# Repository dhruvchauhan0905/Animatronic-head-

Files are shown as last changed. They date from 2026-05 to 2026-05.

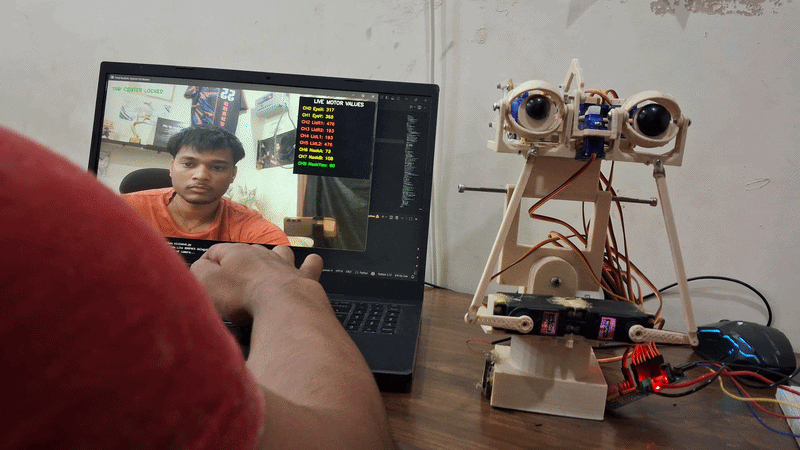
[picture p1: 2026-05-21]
media/Video/gif1-ezgif.com-speed.gif

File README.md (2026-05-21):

# Animatronic-head-
# 🤖 Animatronic Robotic Head — Real-Time Face Tracking

Demo video : https://youtu.be/sOe_zQ1-tDE

> A 9-servo animatronic head that mirrors human facial movements in real time using MediaPipe face mesh tracking, Arduino, and a PCA9685 PWM driver. Includes a full calibration system, physics-based motion control, and predictive compensation for smooth, lag-free neck movement.

## Features

- **Real-time face tracking** via MediaPipe Face Mesh (468 landmarks + iris refinement)
- **9-servo system** — eyes (X/Y), left/right eyelids (2 servos each), and a 3-DOF neck (tilt, vertical, yaw)
- **Calibration phase** — 2-step Y/N confirmation to set user neutral pose before tracking begins
- **Center locking** — neck snaps to neutral when head is stationary, preventing servo drift
- **Eyelid blink detection** — threshold-based open/close state with smooth interpolation
- **Yaw-corrected eye Y** — blends toward individual eye ratio when head turns sharply
- **Perspective-aware eyelid swap** — swaps left/right eyelid state when head turns beyond ±48° yaw
- **Physics-based motion** — per-channel speed, acceleration, and deceleration constants
- **Throttled neck updates** — CH6/CH7 commit target every 17 ms (40% read reduction) to eliminate jitter
- **Predictive target compensation** — 40 ms lookahead cancels serial + processing lag on neck servos
- **Live motor overlay** — real-time HUD showing all 9 channel values colour-coded by deviation

---

## System Architecture

```
Webcam (1280×720)
  │
  ▼
MediaPipe FaceMesh  ──  refine_landmarks=True  ──  iris landmarks 468, 473
  │
  ├─ Iris position (relative to eye corners)       →  Eye X / Y target
  ├─ Forehead / nose / chin distance ratio         →  Neck vertical target
  ├─ Face tilt angle (left/right face points)      →  Neck tilt target
  ├─ Nose-to-face asymmetry ratio                  →  Neck yaw target
  └─ Eyelid landmark distance (159↔145, 386↔374)  →  Blink state
  │
  ▼
Python tracking script
  │  Rolling average smoothing (window = 10 frames)
  │  Center lock, dead zones, yaw damping
  │  Packet: "EyeX,EyeY,LidR1,LidR2,LidL1,LidL2,Neck6,Neck7,Neck8\n"
  │
  ▼
PySerial  ──  COM9  ──  115200 baud
  │
  ▼
Arduino Uno
  │  readVisionSerial()  — parses comma-delimited packet
  │  updateNeck67()      — throttle + predictive commit every 17 ms
  │  driveEyeY()         — hybrid physics for CH1
  │  drivePhysics67()    — physics for CH6/CH7
  │  drivePhysics8()     — physics for CH8
  │  loop delay(10)      — 100 Hz
  │
  ▼
PCA9685  (I2C, 60 Hz PWM)
  │
  ├─ CH0  Eye X     (direct pulse)
  ├─ CH1  Eye Y     (physics)
  ├─ CH2  LidR1     (direct pulse)
  ├─ CH3  LidR2     (direct pulse)
  ├─ CH4  LidL1     (direct pulse)
  ├─ CH5  LidL2     (direct pulse)
  ├─ CH6  Neck A    (throttle + physics)
  ├─ CH7  Neck B    (throttle + physics)
  └─ CH8  Neck Yaw  (physics)
```

---

## Channel Mapping

| Channel | Name | Drive type | Neutral | Range | Notes |
|---|---|---|---|---|---|
| CH0 | Eye X | Direct pulse | 330 | 195 – 465 | Horizontal iris tracking |
| CH1 | Eye Y | Physics | 350 | 260 – 445 | Vertical iris tracking |
| CH2 | Right Eyelid 1 | Direct pulse | 330 | 193 – 477 | Open = 477, Closed = 330 |
| CH3 | Right Eyelid 2 | Direct pulse | 330 | 193 – 477 | Open = 193, Closed = 330 |
| CH4 | Left Eyelid 1 | Direct pulse | 330 | 193 – 477 | Open = 193, Closed = 330 |
| CH5 | Left Eyelid 2 | Direct pulse | 330 | 193 – 477 | Open = 477, Closed = 330 |
| CH6 | Neck A (vertical + tilt) | Throttled physics | 90° | 5° – 175° | Paired with CH7 |
| CH7 | Neck B (vertical + tilt) | Throttled physics | 90° | 5° – 175° | Paired with CH6 |
| CH8 | Neck Yaw | Physics | 90° | 3° – 175° | Maps yaw ratio −0.30 → 0.30 |

> CH6 and CH7 are driven together. Vertical lift adds to both equally; tilt adds equally in the same direction, producing roll from the difference.

---

## Serial Packet Format

Python sends one ASCII line per frame over serial:

```
{EyeX},{EyeY},{LidR1},{LidR2},{LidL1},{LidL2},{Neck6},{Neck7},{NeckYaw}\n
```

Example:
```
328,352,477,193,193,477,94,86,91
```

CH0–CH5 are raw PCA9685 pulse counts. CH6–CH8 are angles in degrees (0–180), converted to pulses on the Arduino side via `angleToPulse()`.

> ⚠️ **Baud rate mismatch in current code:** `face_tracker.py` opens serial at **9600** but `animatronic_head.ino` uses `Serial.begin(115200)`. Set both to **115200** — see Setup section.

---

## Motion Tuning

### Arduino — CH1 Eye Y physics

```cpp
float eyeMaxSpeed      = 9.5;    // max degrees per loop tick
float eyeAccel         = 0.55;   // acceleration ramp
float eyeDecel         = 0.78;   // deceleration multiplier
float eyeDecelDistance = 10;     // distance from target to begin braking
```

### Arduino — CH6 / CH7 Neck (vertical + tilt)

```cpp
float maxSpeed67      = 9.52;    // 40% raised from original 6.8
float accel67         = 0.336;   // 40% raised from original 0.24
float decel67         = 0.84;
float decelDistance67 = 16;

const unsigned long NECK67_INTERVAL = 17;    // ms — commit throttle
const float         LOOKAHEAD_SEC   = 0.040; // 40 ms predictive lead
```

Incoming CH6/CH7 targets are **averaged** across all serial packets received in the 17 ms window, then a velocity estimate is computed and the target is nudged 40 ms ahead before it is handed to the physics driver. This removes the lag introduced by serial buffering and processing delay.

### Arduino — CH8 Neck Yaw

```cpp
float maxSpeed8      = 5.6;
float accel8         = 0.18;
float decel8         = 0.86;
float decelDistance8 = 18;
```

### Python — Smoothing factors

| Parameter | Value | Effect |
|---|---|---|
| Eye X blend | 0.90 | Very fast, near-instant |
| Eye Y blend | 0.67 | Slightly damped |
| Eyelid blend | 0.39 | Slow, natural-looking blink |
| Yaw / vertical / tilt window | 10 frames | Rolling average |

### Python — Center lock thresholds

| Lock | Engages when | Releases when |
|---|---|---|
| Neck center (CH6/CH7) | total error < 5 | total error > 13 |
| Yaw center (CH8) | \|avgYaw\| < 0.04 | \|avgYaw\| > 0.09 |

When locked, the corresponding channels hold exactly at their neutral value regardless of small sensor noise.

---

## Calibration

On launch the script runs a calibration loop before tracking starts.

1. Sit in your neutral resting position facing the camera
2. Wait at least 10 seconds for stable face detection
3. Press **`Y`** — first confirmation, captures current pose as tentative reference
4. Press **`Y`** again — confirms and locks the reference zero
5. Press **`N`** at any step to reset and recapture

The calibration stores:

| Variable | What it captures |
|---|---|
| `baseEyeRelX / baseEyeRelY` | Iris position normalised to eye corner span |
| `baseTop / baseBottom` | Forehead-to-nose and nose-to-chin ratios (normalised to face width) |
| `baseTilt` | Face roll angle in degrees |
| `baseYaw` | Nose-to-face-edge asymmetry ratio |

All live values are computed as **deltas from this reference**, so the robot stays centred regardless of where you sit relative to the camera.

---

## Eyelid Logic

Blink detection uses vertical distance between eyelid landmarks:

```
Left eye:   lm[159] (top lid)  ↔  lm[145] (bottom lid)
Right eye:  lm[386] (top lid)  ↔  lm[374] (bottom lid)
```

| Event | Threshold | Result |
|---|---|---|
| Opening | distance > 0.0132 | State → Open |
| Closing | distance < 0.0108 | State → Closed |

Hysteresis between the two thresholds prevents rapid state flicker.

When **yaw exceeds ±48°**, the left and right eyelid states are swapped — at that angle the camera perspective reverses which eye appears to be blinking.

---

## Hardware

### Components

| Component | Qty | Notes |
|---|---|---|
| Arduino Uno | 1 | Microcontroller |
| PCA9685 16-ch PWM driver | 1 | I2C, 60 Hz |
| MG996R servo | 3 | Neck — CH6, CH7, CH8 |
| SG90 servo | 6 | Eyes — CH0, CH1 + eyelids — CH2–CH5 |
| 5V 5A SMPS | 1 | Powers servos via PCA9685 V+ terminal |
| Webcam | 1 | Face tracking input |

### Wiring

```
Arduino Uno              PCA9685
-----------              -------
5V          ──────────▶  VCC
GND         ──────────▶  GND
A4 (SDA)    ──────────▶  SDA
A5 (SCL)    ──────────▶  SCL

External PSU (5V 5A)     PCA9685
--------------------     -------
+           ──────────▶  V+  (power terminal)
−           ──────────▶  GND (power terminal)
```

> ⚠️ Never power servos from Arduino 5V. Always use the external PSU through the PCA9685 V+ terminal.

### Pulse range

```cpp
#define SERVOMIN 140   // ≈ 0°
#define SERVOMAX 520   // ≈ 180°
```

---

## Setup

### 1. Python dependencies

```bash
pip install mediapipe opencv-python pyserial
```

### 2. Arduino libraries

Install via Arduino Library Manager:
- `Adafruit PWM Servo Driver Library`
- `Wire` (built-in)

### 3. Upload firmware

Open `firmware/animatronic_head.ino`, select **Arduino Uno** and your COM port, then upload.

### 4. Fix baud rate (important)

In `tracking/face_tracker.py`, change line 4:
```python
# Before
arduino = serial.Serial('COM9', 9600)

# After
arduino = serial.Serial('COM9', 115200)   # match Arduino sketch
```

Also update `'COM9'` to your actual port (`/dev/ttyUSB0` on Linux, `/dev/cu.usbmodem...` on Mac).

### 5. Run the tracker

```bash
python tracking/face_tracker.py
```

Follow the calibration prompt on screen. Press **`Y`** twice to confirm neutral pose. Press **`ESC`** to quit.

---

## Repository Structure

```
animatronic-head/
├── README.md
├── firmware/
│   └── animatronic_head.ino      # Arduino sketch
├── tracking/
│   └── face_tracker.py           # Python face tracking + serial bridge
├── cad/
│   ├── eye_hemisphere.stl
│   ├── neck_mechanism.stl
│   └── source/                   # Fusion 360 .f3d source files
├── media/
│   ├── demo.gif
│   ├── wiring_diagram.svg
│   └── photos/
└── docs/
    └── wiring.md
```

---

## 3D Printing

| Setting | Value |
|---|---|
| Material | PLA |
| Layer height | 0.2 mm |
| Infill | 20% |
| Supports | Yes (neck assembly) |

---

## Author

**Dhruv** — Engineering student, Delhi  
Interests: robotics, animatronics, hardware systems  
GitHub: [@dhruvchauhan0905](https://github.com/dhruvchauhan0905)

---

## License

MIT License — free to use, modify, and build on.

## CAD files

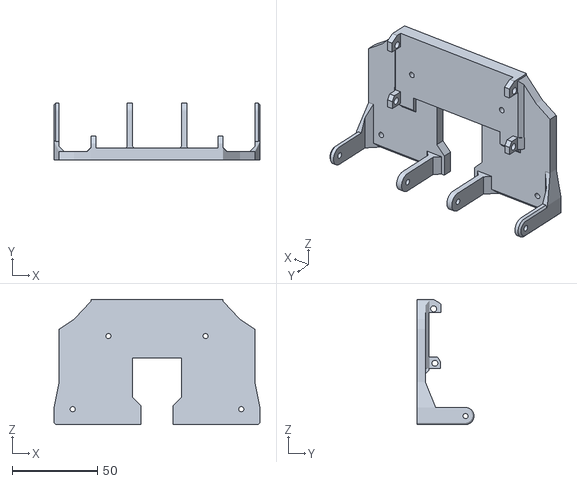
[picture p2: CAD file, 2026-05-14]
cad/eyes/Main Base.stl
121.0 x 33.5 x 73.5

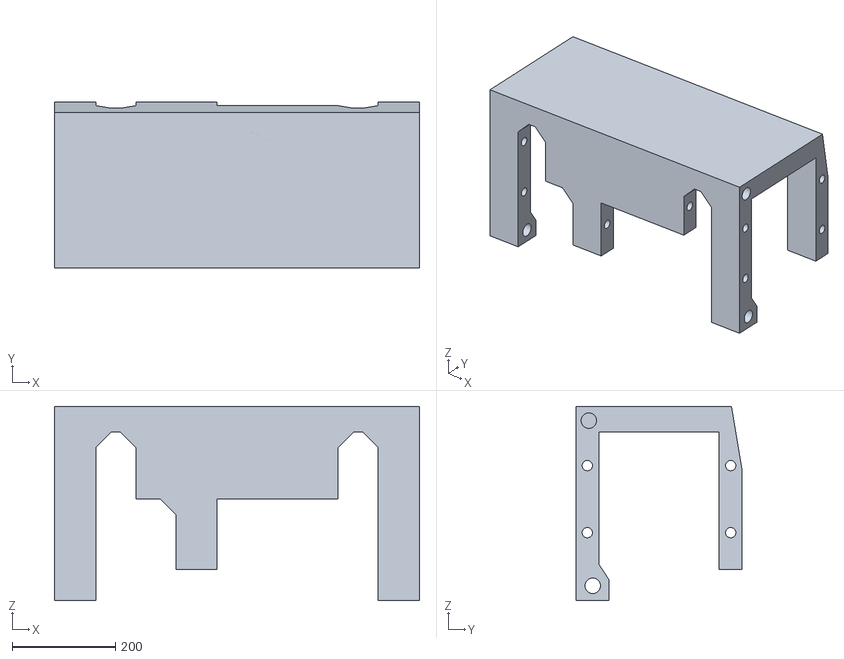
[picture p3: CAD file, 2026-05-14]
cad/eyes/Servo Block2.stl
707.7 x 321.0 x 376.8

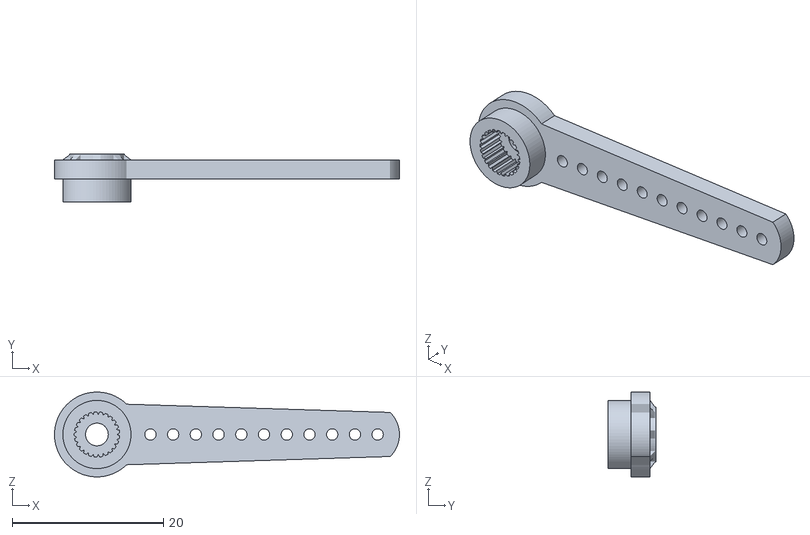
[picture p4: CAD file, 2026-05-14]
cad/neck/servohorn(+2).stl
45.5 x 6.30 x 11.2

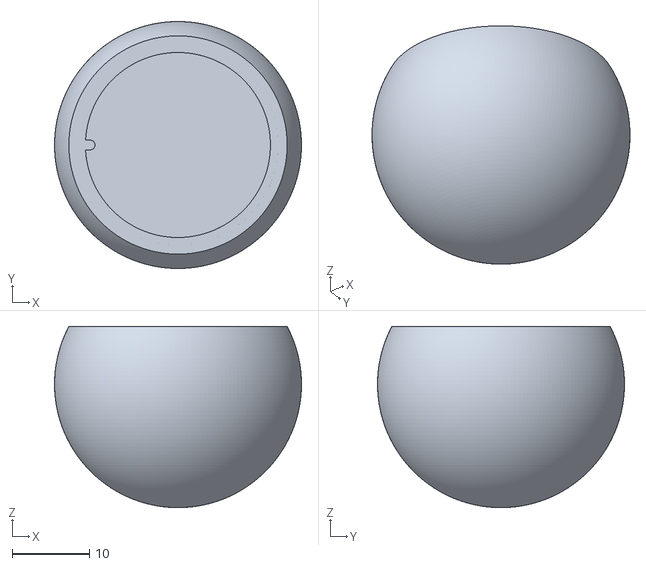
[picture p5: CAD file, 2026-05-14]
cad/eyes/PlaceHolder Eye (x2).stl
32.0 x 32.0 x 23.5

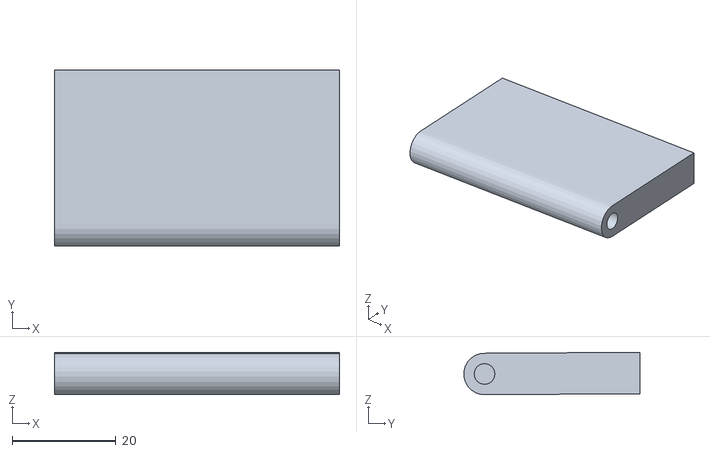
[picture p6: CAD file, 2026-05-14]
cad/neck/felxion and extension lever_.stl
55.0 x 34.0 x 8.17

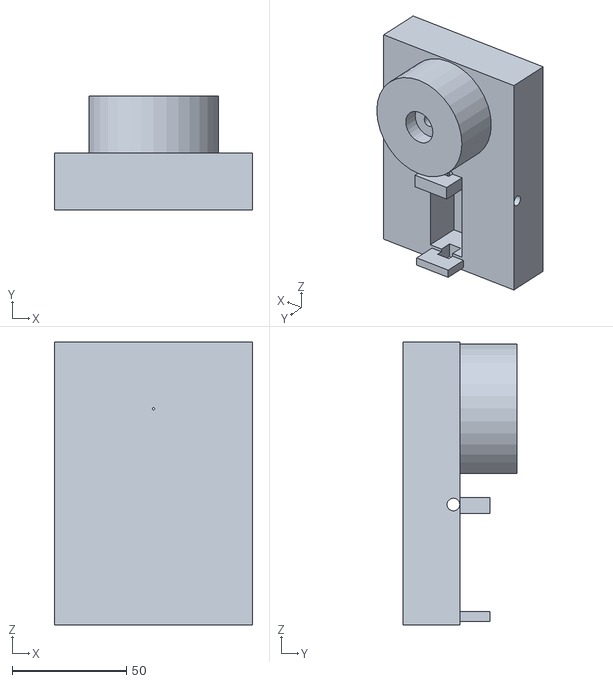
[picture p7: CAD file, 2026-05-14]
cad/neck/neckbase.stl
86.5 x 50.0 x 123.6

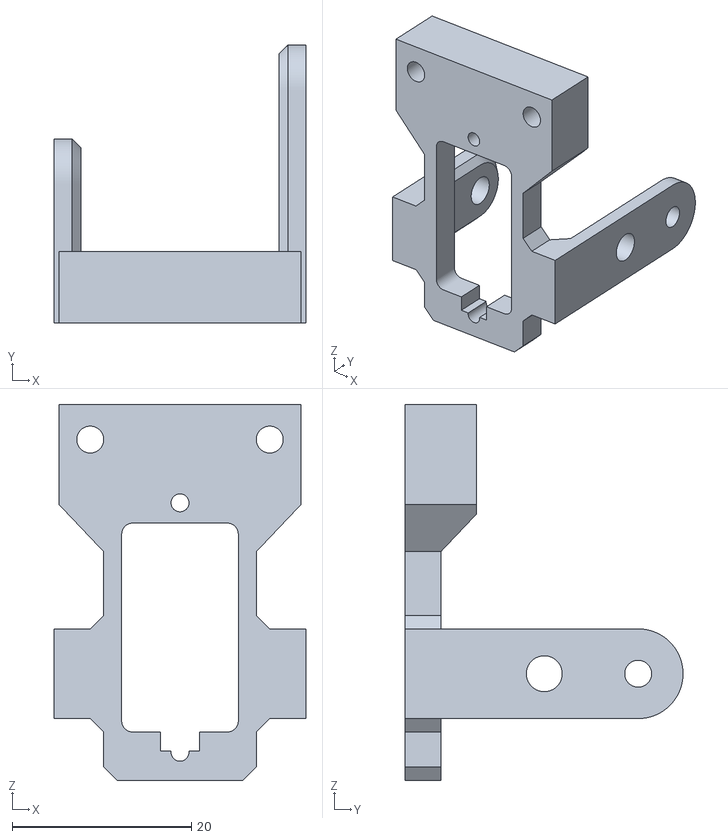
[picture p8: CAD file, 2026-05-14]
cad/eyes/Sub Base.stl
28.1 x 31.0 x 41.9

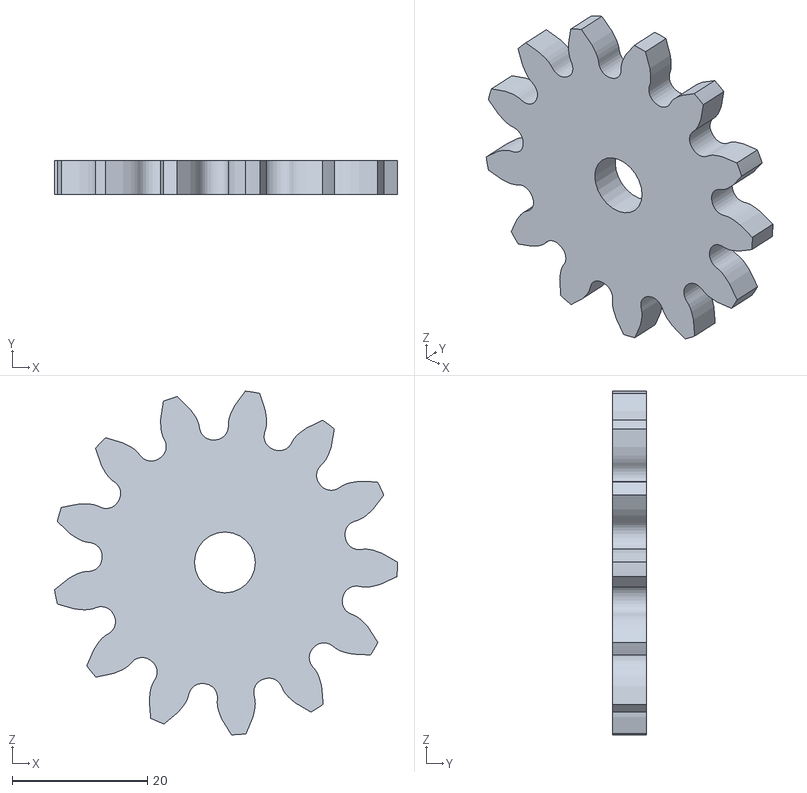
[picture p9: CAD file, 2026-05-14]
cad/neck/drivergear for roatation _.stl
50.7 x 5.00 x 50.8

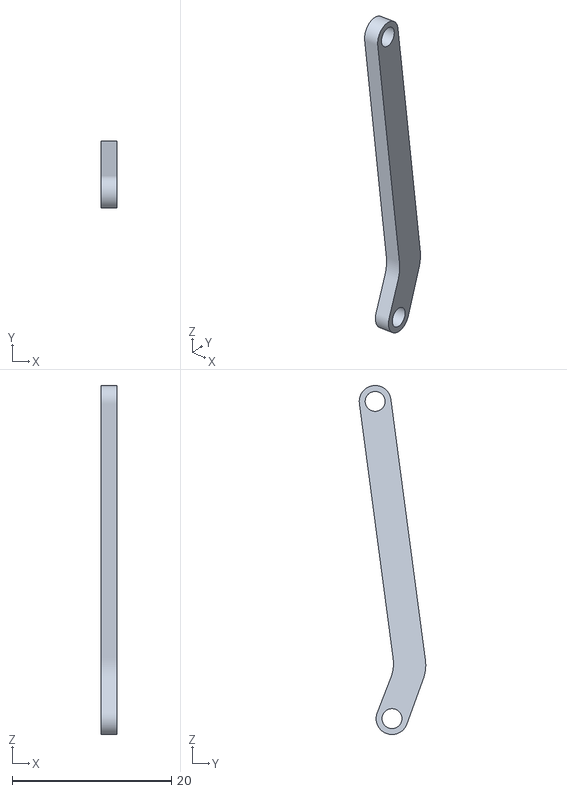
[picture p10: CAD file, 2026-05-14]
cad/eyes/Top Lid Link (x2).stl
2.00 x 8.36 x 43.9

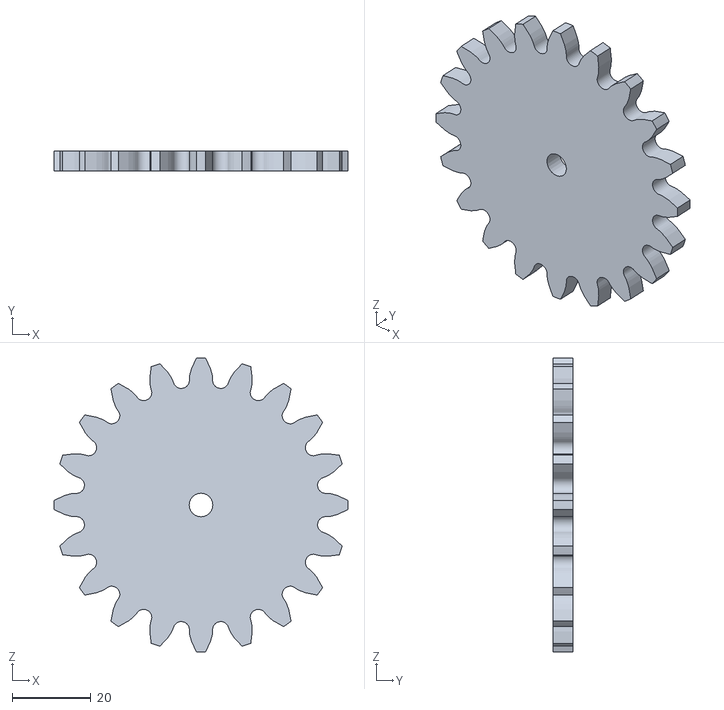
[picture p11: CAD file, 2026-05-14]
cad/neck/drivengear for roation _.stl
74.8 x 5.00 x 74.8

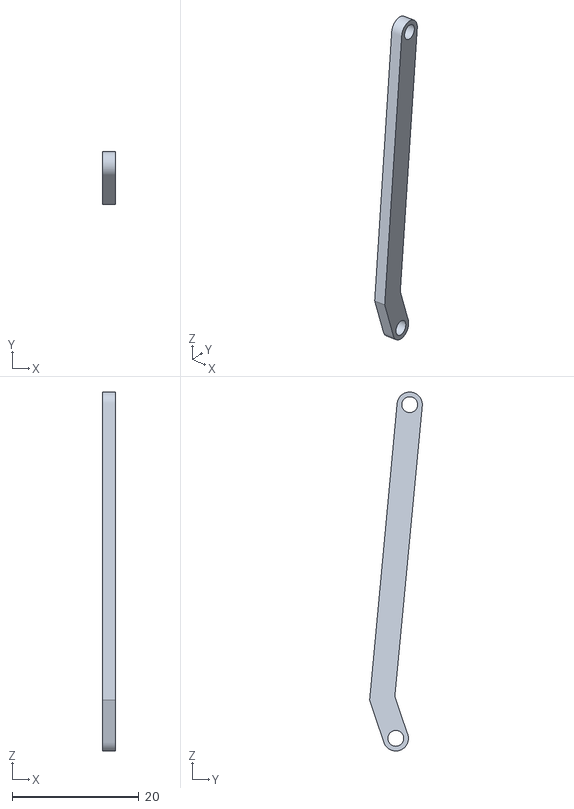
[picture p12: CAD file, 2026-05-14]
cad/eyes/Bottom Lid Link (x2).stl
2.00 x 8.33 x 56.7

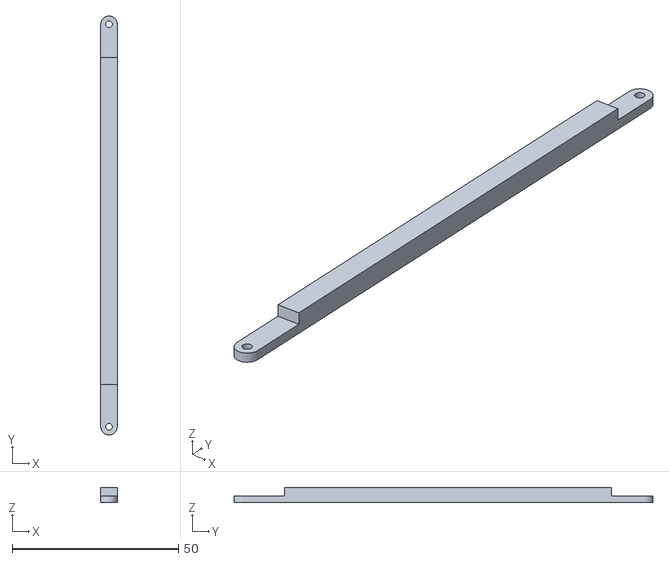
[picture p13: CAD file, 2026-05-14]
cad/neck/flexion and extensions pulley(+2)_.stl
5.00 x 126.0 x 4.50

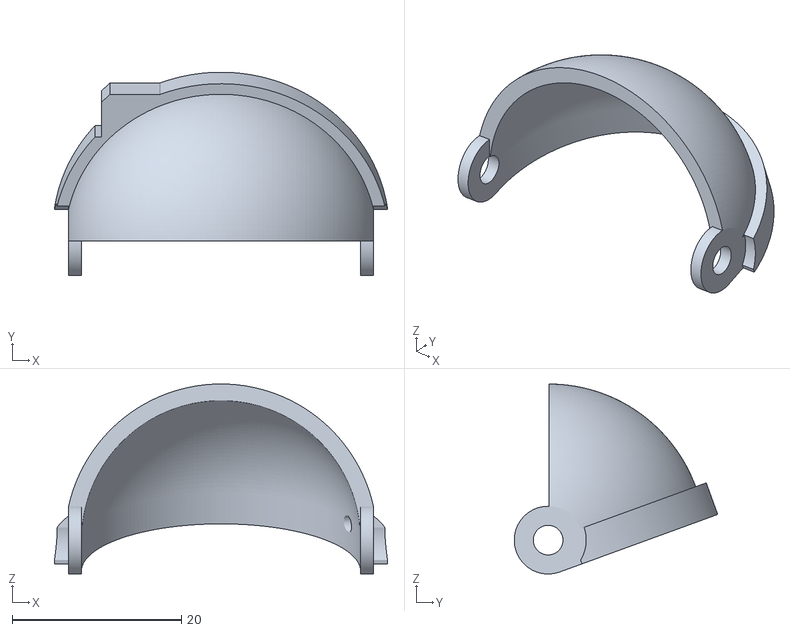
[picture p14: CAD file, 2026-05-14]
cad/eyes/Top Right Lid.stl
39.3 x 24.0 x 22.4

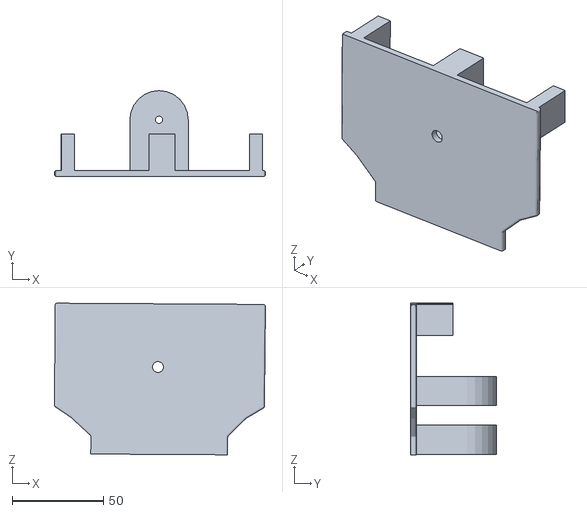
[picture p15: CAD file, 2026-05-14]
cad/neck/subbase.stl
115.6 x 47.0 x 83.1

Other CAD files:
cad/eyes/Three-Point Connector.stl
cad/neck/sidebend lever_.stl
cad/eyes/Eye Holder.stl
cad/eyes/Bottom Right Lid.stl
cad/eyes/Bottom Left Lid.stl
cad/eyes/Eye Adaptor (x2).stl
cad/eyes/Fork (x2).stl
cad/eyes/Top Left Lid.stl
cad/eyes/Y-Arm.stl

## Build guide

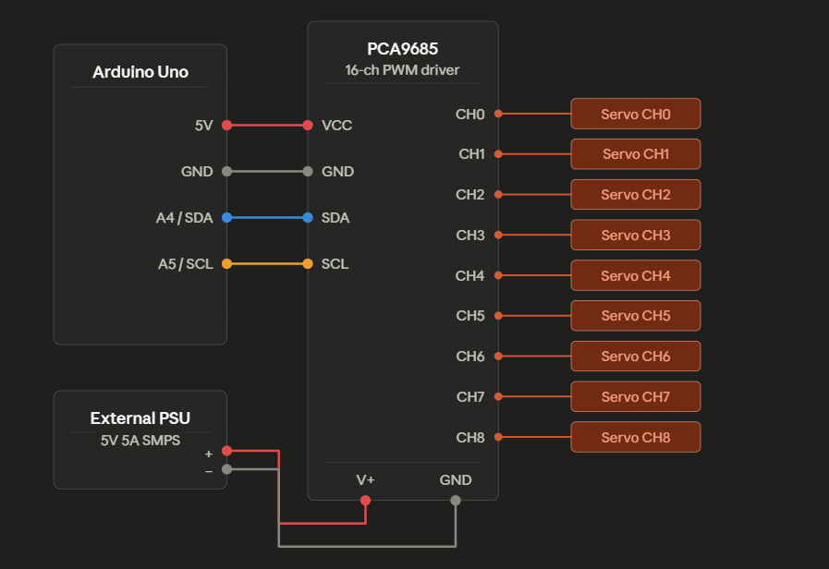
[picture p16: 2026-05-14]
media/wiring diagram .png

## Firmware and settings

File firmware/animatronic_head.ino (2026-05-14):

#include <Wire.h>
#include <Adafruit_PWMServoDriver.h>

Adafruit_PWMServoDriver pwm = Adafruit_PWMServoDriver();

#define SERVOMIN 140
#define SERVOMAX 520

int pulseX = 330, pulseY = 375;
int ch2 = 330, ch3 = 330, ch4 = 330, ch5 = 330;

// ===== CH1 HYBRID EYE Y — original unchanged =====
float eyeYTarget = 375;
float eyeYPos = 375;
float eyeYVel = 0;

// ===== CH8 YAW — original unchanged =====
float target8 = 90, pos8 = 90, vel8 = 0;

String incoming = "";

// ===== CH1 EYE Y CONSTANTS — original unchanged =====
float eyeMaxSpeed      = 9.5;
float eyeAccel         = 0.55;
float eyeDecel         = 0.78;
float eyeDecelDistance = 10;

// ===== CH6/CH7 CONSTANTS — speed raised 40% from original =====
// Original: maxSpeed67=6.8, accel67=0.24
// x1.4   : maxSpeed67=9.52, accel67=0.336
float maxSpeed67      = 9.52;
float accel67         = 0.336;
float decel67         = 0.84;   // original unchanged
float decelDistance67 = 16;     // original unchanged

// ===== CH8 CONSTANTS — original unchanged =====
float maxSpeed8      = 5.6;
float accel8         = 0.18;
float decel8         = 0.86;
float decelDistance8 = 18;

// ==========================================================
//  CH6/CH7 THROTTLE + PREDICTIVE COMPENSATION
//
//  40% read reduction: loop runs every 10ms (100Hz).
//  Original = 100 target updates/sec.
//  40% less  = 60 updates/sec = update every 17ms.
//  So ch6/ch7 target only commits every 17ms.
//
//  Predictive compensation: every commit we calculate how
//  fast the target is moving (degrees/sec) and look 40ms
//  ahead. Motor aims at where the neck WILL be, not where
//  it was — this cancels the serial+processing lag.
// ==========================================================
const unsigned long NECK67_INTERVAL = 17;   // ms — 40% less than 10ms loop
const float         LOOKAHEAD_SEC   = 0.040; // 40ms prediction window

float accum6 = 0, accum7 = 0;
int   accumCount = 0;

float committedTarget6 = 90.0;
float committedTarget7 = 90.0;

float prevAvg6 = 90.0, prevAvg7 = 90.0;

float pos6 = 90, vel6 = 0;
float pos7 = 90, vel7 = 0;

unsigned long lastNeck67Update = 0;

// ----------------------------------------------------------
int angleToPulse(float angle) {
  return map((int)angle, 0, 180, SERVOMIN, SERVOMAX);
}

// ----------------------------------------------------------
void readVisionSerial() {
  while (Serial.available()) {
    char c = Serial.read();

    if (c == '\n') {
      int p1 = incoming.indexOf(',');
      int p2 = incoming.indexOf(',', p1 + 1);
      int p3 = incoming.indexOf(',', p2 + 1);
      int p4 = incoming.indexOf(',', p3 + 1);
      int p5 = incoming.indexOf(',', p4 + 1);
      int p6 = incoming.indexOf(',', p5 + 1);
      int p7 = incoming.indexOf(',', p6 + 1);
      int p8 = incoming.indexOf(',', p7 + 1);

      if (p1>0 && p2>0 && p3>0 && p4>0 && p5>0 && p6>0 && p7>0 && p8>0) {
        pulseX = incoming.substring(0,      p1).toInt();
        pulseY = incoming.substring(p1 + 1, p2).toInt();
        ch2    = incoming.substring(p2 + 1, p3).toInt();
        ch3    = incoming.substring(p3 + 1, p4).toInt();
        ch4    = incoming.substring(p4 + 1, p5).toInt();
        ch5    = incoming.substring(p5 + 1, p6).toInt();

        // Accumulate ch6/ch7 — commit happens on timer below
        float raw6 = incoming.substring(p6 + 1, p7).toFloat();
        float raw7 = incoming.substring(p7 + 1, p8).toFloat();
        target8    = incoming.substring(p8 + 1).toFloat();

        eyeYTarget = pulseY;

        accum6 += raw6;
        accum7 += raw7;
        accumCount++;
      }
      incoming = "";
    }
    else {
      incoming += c;
    }
  }
}

// ----------------------------------------------------------
//  Runs every loop. Only commits a new target to ch6/ch7
//  every 17ms (40% less than 10ms loop = 40% read reduction).
//  Applies predictive compensation to remove lag.
// ----------------------------------------------------------
void updateNeck67() {
  unsigned long now = millis();
  if (now - lastNeck67Update < NECK67_INTERVAL) return;

  float dt = (now - lastNeck67Update) / 1000.0;  // actual elapsed seconds
  lastNeck67Update = now;

  if (accumCount > 0) {
    float avg6 = accum6 / accumCount;
    float avg7 = accum7 / accumCount;

    // Velocity of target in degrees/sec
    float targetVel6 = (avg6 - prevAvg6) / dt;
    float targetVel7 = (avg7 - prevAvg7) / dt;

    // Predict where target will be LOOKAHEAD_SEC from now
    // This compensates for serial delay + processing delay
    float predicted6 = avg6 + targetVel6 * LOOKAHEAD_SEC;
    float predicted7 = avg7 + targetVel7 * LOOKAHEAD_SEC;

    // Clamp prediction to safe servo range
    committedTarget6 = constrain(predicted6, 5.0, 175.0);
    committedTarget7 = constrain(predicted7, 5.0, 175.0);

    prevAvg6 = avg6;
    prevAvg7 = avg7;

    accum6 = 0;
    accum7 = 0;
    accumCount = 0;
  }
}

// ===== ORIGINAL PHYSICS FUNCTIONS — structure unchanged =====

void driveEyeY(float &pos, float &vel, float target) {
  float error = target - pos;
  if (abs(error) > eyeDecelDistance) {
    vel += (error > 0 ? eyeAccel : -eyeAccel);
  } else {
    vel *= eyeDecel;
  }
  vel = constrain(vel, -eyeMaxSpeed, eyeMaxSpeed);
  if (abs(error) < 0.3) vel = 0;
  pos += vel;
  pos  = constrain(pos, 260, 445);
}

void drivePhysics67(float &pos, float &vel, float target,
                    float maxSpeed, float accel, float decel, float decelDistance) {
  float error = target - pos;
  if (abs(error) > decelDistance) {
    vel += (error > 0 ? accel : -accel);
  } else {
    vel *= decel;
  }
  vel = constrain(vel, -maxSpeed, maxSpeed);
  if (abs(error) < 0.4) vel = 0;
  pos += vel;
  pos  = constrain(pos, 3, 178);
}

void drivePhysics8(float &pos, float &vel, float target,
                   float maxSpeed, float accel, float decel, float decelDistance) {
  float error = target - pos;
  if (abs(error) > decelDistance) {
    vel += (error > 0 ? accel : -accel);
  } else {
    vel *= decel;
  }
  vel = constrain(vel, -maxSpeed, maxSpeed);
  if (abs(error) < 0.4) vel = 0;
  pos += vel;
  pos  = constrain(pos, 3, 178);
}

// ----------------------------------------------------------
void setup() {
  Serial.begin(115200);
  pwm.begin();
  pwm.setPWMFreq(60);
  lastNeck67Update = millis();
}

void loop() {

  readVisionSerial();
  updateNeck67();

  // CH0 — direct, original
  pwm.setPWM(0, 0, pulseX);

  // CH1 — hybrid eye Y, original
  driveEyeY(eyeYPos, eyeYVel, eyeYTarget);
  pwm.setPWM(1, 0, (int)eyeYPos);

  // CH2-5 — eyelids direct, original
  pwm.setPWM(2, 0, ch2);
  pwm.setPWM(3, 0, ch3);
  pwm.setPWM(4, 0, ch4);
  pwm.setPWM(5, 0, ch5);

  // CH6/CH7 — throttled + predicted target, original physics function
  drivePhysics67(pos6, vel6, committedTarget6, maxSpeed67, accel67, decel67, decelDistance67);
  drivePhysics67(pos7, vel7, committedTarget7, maxSpeed67, accel67, decel67, decelDistance67);
  pwm.setPWM(6, 0, angleToPulse(pos6));
  pwm.setPWM(7, 0, angleToPulse(pos7));

  // CH8 — yaw, original unchanged
  drivePhysics8(pos8, vel8, target8, maxSpeed8, accel8, decel8, decelDistance8);
  pwm.setPWM(8, 0, angleToPulse(pos8));

  delay(10);
}

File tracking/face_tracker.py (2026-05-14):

import cv2
import mediapipe as mp
import serial
import time
import math

arduino = serial.Serial('COM9', 9600)
time.sleep(2)

mp_face_mesh = mp.solutions.face_mesh
face_mesh = mp_face_mesh.FaceMesh(refine_landmarks=True)

cap = cv2.VideoCapture(0)

ROBOT_EYE_X_CENTER = 330
ROBOT_EYE_Y_CENTER = 350
ROBOT_NECK6_CENTER = 90
ROBOT_NECK7_CENTER = 90
ROBOT_NECK8_CENTER = 90

smoothX = ROBOT_EYE_X_CENTER
smoothY = ROBOT_EYE_Y_CENTER
L2 = L3 = R4 = R5 = 330

targetNeck6 = ROBOT_NECK6_CENTER
targetNeck7 = ROBOT_NECK7_CENTER
targetNeck8 = ROBOT_NECK8_CENTER

yawHistory = []
verticalHistory = []
tiltHistory = []

lastLeftX = None
lastRightX = None

baseTop = 0
baseBottom = 0
baseTilt = 0
baseYaw = 0
baseEyeRelX = 0
baseEyeRelY = 0

neckCenterLocked = False
yawCenterLocked = False

leftEyeStateOpen = True
rightEyeStateOpen = True

def map_range(value, in_min, in_max, out_min, out_max):
    value = max(min(value, in_max), in_min)
    return int((value - in_min) * (out_max - out_min) / (in_max - in_min) + out_min)

def distance(a, b):
    return math.sqrt((a.x-b.x)**2 + (a.y-b.y)**2)

def easeBlend(t):
    t = max(0.0,min(1.0,t))
    return (1 - math.cos(math.pi*t))/2

def motorColor(val, neutral):
    diff = abs(val-neutral)
    if diff < 8:
        return (0,255,0)
    elif diff < 30:
        return (0,255,255)
    else:
        return (0,0,255)

def drawMotorValues(frame, motors):
    cv2.rectangle(frame,(910,10),(1270,380),(25,25,25),-1)
    cv2.putText(frame,"LIVE MOTOR VALUES",(980,35),
                cv2.FONT_HERSHEY_SIMPLEX,0.75,(255,255,255),2)

    y = 70
    for name,val,neutral in motors:
        color = motorColor(val,neutral)
        cv2.putText(frame,f"{name}: {int(val)}",(930,y),
                    cv2.FONT_HERSHEY_SIMPLEX,0.62,color,2)
        y += 33

print("Sit comfortably in front of camera...")

# ================= CALIBRATION =================
start_time = time.time()
confirmed = False
tentative_capture = False
temp_data = {}

while not confirmed:
    ret, frame = cap.read()
    frame = cv2.flip(frame,1)
    frame = cv2.resize(frame,(1280,720))
    rgb = cv2.cvtColor(frame, cv2.COLOR_BGR2RGB)
    results = face_mesh.process(rgb)

    h,w,_ = frame.shape

    if results.multi_face_landmarks:
        lm = results.multi_face_landmarks[0].landmark
        xs = [int(p.x*w) for p in lm]
        ys = [int(p.y*h) for p in lm]
        x1,x2 = min(xs), max(xs)
        y1,y2 = min(ys), max(ys)

        cv2.rectangle(frame,(x1,y1),(x2,y2),(0,255,0),2)

        if not tentative_capture:
            if time.time()-start_time > 10:
                cv2.putText(frame,"SET THIS AS USER NEUTRAL? Press Y / N",(20,50),
                            cv2.FONT_HERSHEY_SIMPLEX,0.8,(0,255,255),2)
        else:
            cv2.putText(frame,"CONFIRM USER REFERENCE ZERO? Press Y / N",(20,50),
                        cv2.FONT_HERSHEY_SIMPLEX,0.8,(0,255,255),2)

    cv2.imshow("Calibration",frame)
    key = cv2.waitKey(1) & 0xFF

    if key == ord('y') and results.multi_face_landmarks and not tentative_capture:
        lm = results.multi_face_landmarks[0].landmark
        forehead = lm[10]; nose = lm[1]; chin = lm[152]
        leftFace = lm[234]; rightFace = lm[454]
        irisL = lm[468]; irisR = lm[473]

        leftRatioX = (irisL.x-lm[33].x)/(lm[133].x-lm[33].x)
        rightRatioX = (irisR.x-lm[362].x)/(lm[263].x-lm[362].x)
        leftRatioY = (irisL.y-lm[159].y)/(lm[145].y-lm[159].y)
        rightRatioY = (irisR.y-lm[386].y)/(lm[374].y-lm[386].y)

        temp_data["baseEyeRelX"]=(leftRatioX+rightRatioX)/2
        temp_data["baseEyeRelY"]=(leftRatioY+rightRatioY)/2

        faceWidth = distance(leftFace,rightFace)
        temp_data["baseTop"]=distance(forehead,nose)/faceWidth
        temp_data["baseBottom"]=distance(nose,chin)/faceWidth
        temp_data["baseTilt"]=math.degrees(math.atan2((rightFace.y-leftFace.y),(rightFace.x-leftFace.x)))

        dL = abs(nose.x-leftFace.x)
        dR = abs(rightFace.x-nose.x)
        temp_data["baseYaw"]=(dR-dL)/(dR+dL)

        tentative_capture=True

    elif key == ord('y') and tentative_capture:
        baseTop=temp_data["baseTop"]
        baseBottom=temp_data["baseBottom"]
        baseTilt=temp_data["baseTilt"]
        baseYaw=temp_data["baseYaw"]
        baseEyeRelX=temp_data["baseEyeRelX"]
        baseEyeRelY=temp_data["baseEyeRelY"]
        confirmed=True

    elif key == ord('n'):
        tentative_capture=False
        start_time=time.time()-5

cv2.destroyWindow("Calibration")

# ================= MAIN LOOP =================
while True:
    ret, frame = cap.read()
    if not ret:
        break

    frame = cv2.flip(frame,1)
    frame = cv2.resize(frame,(1280,720))
    rgb = cv2.cvtColor(frame, cv2.COLOR_BGR2RGB)
    results = face_mesh.process(rgb)

    if results.multi_face_landmarks:
        lm = results.multi_face_landmarks[0].landmark
        h,w,_ = frame.shape

        leftOpen = distance(lm[159],lm[145])
        rightOpen = distance(lm[386],lm[374])

        if leftOpen > 0.0132: leftEyeStateOpen = True
        elif leftOpen < 0.0108: leftEyeStateOpen = False

        if rightOpen > 0.0132: rightEyeStateOpen = True
        elif rightOpen < 0.0108: rightEyeStateOpen = False

        irisL = lm[468]; irisR = lm[473]
        cv2.circle(frame,(int(irisL.x*w),int(irisL.y*h)),2,(0,255,0),-1)
        cv2.circle(frame,(int(irisR.x*w),int(irisR.y*h)),2,(255,0,0),-1)

        leftRatioX = (irisL.x-lm[33].x)/(lm[133].x-lm[33].x)
        rightRatioX = (irisR.x-lm[362].x)/(lm[263].x-lm[362].x)
        avgRelX = (leftRatioX+rightRatioX)/2

        leftRatioY = (irisL.y-lm[159].y)/(lm[145].y-lm[159].y)
        rightRatioY = (irisR.y-lm[386].y)/(lm[374].y-lm[386].y)
        avgRelY = (leftRatioY+rightRatioY)/2

        forehead = lm[10]; noseMain = lm[1]; chin = lm[152]
        leftFace = lm[234]; rightFace = lm[454]

        faceWidth = distance(leftFace,rightFace)
        topNorm = distance(forehead,noseMain)/faceWidth
        bottomNorm = distance(noseMain,chin)/faceWidth
        tiltAngle = math.degrees(math.atan2((rightFace.y-leftFace.y),(rightFace.x-leftFace.x)))

        dLtemp = abs(noseMain.x-leftFace.x)
        dRtemp = abs(rightFace.x-noseMain.x)
        yawTemp = ((dRtemp-dLtemp)/(dRtemp+dLtemp)) - baseYaw

        yawDamp = max(0.35,1-abs(yawTemp)*2.0)

        rawVertical = ((baseTop-topNorm)+(bottomNorm-baseBottom))*950
        rawTilt = (tiltAngle-baseTilt)*3.0*yawDamp

        verticalHistory.append(rawVertical)
        tiltHistory.append(rawTilt)

        if len(verticalHistory)>10: verticalHistory.pop(0)
        if len(tiltHistory)>10: tiltHistory.pop(0)

        verticalRatio = sum(verticalHistory)/len(verticalHistory)
        horizontalTilt = sum(tiltHistory)/len(tiltHistory)

        neckError = abs(verticalRatio)+abs(horizontalTilt)

        if neckCenterLocked:
            if neckError > 13: neckCenterLocked = False
        else:
            if neckError < 5: neckCenterLocked = True
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
